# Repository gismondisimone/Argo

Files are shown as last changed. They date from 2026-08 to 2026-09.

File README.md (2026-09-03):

# ARGO - Halve The Time, Double The Help!

### A Smart System Created To Help Archaeologists.

---

## Renders
---

## BOM
All the bits and pieces needed can be found **[here](Production/BOM.md)**.

---

## What is This?
Argo is a **smart** system created to help **archaeologists**. It's the first of its kind to be able to digitalize archaeological fragments via scanning, create 3D models of the pieces and categorize them systematically, doing all of this quickly and **on-site**.

## Team
Composed of senior students Elisabetta Liliana Albanese and Rossella Fumai (Applied Sciences) and junior student Simone Gismondi (Traditional Track) from "Edoardo Amaldi" High School in Italy, our team discovered a passion for robotics through hands-on school projects in coding, mechanics, and electronics.

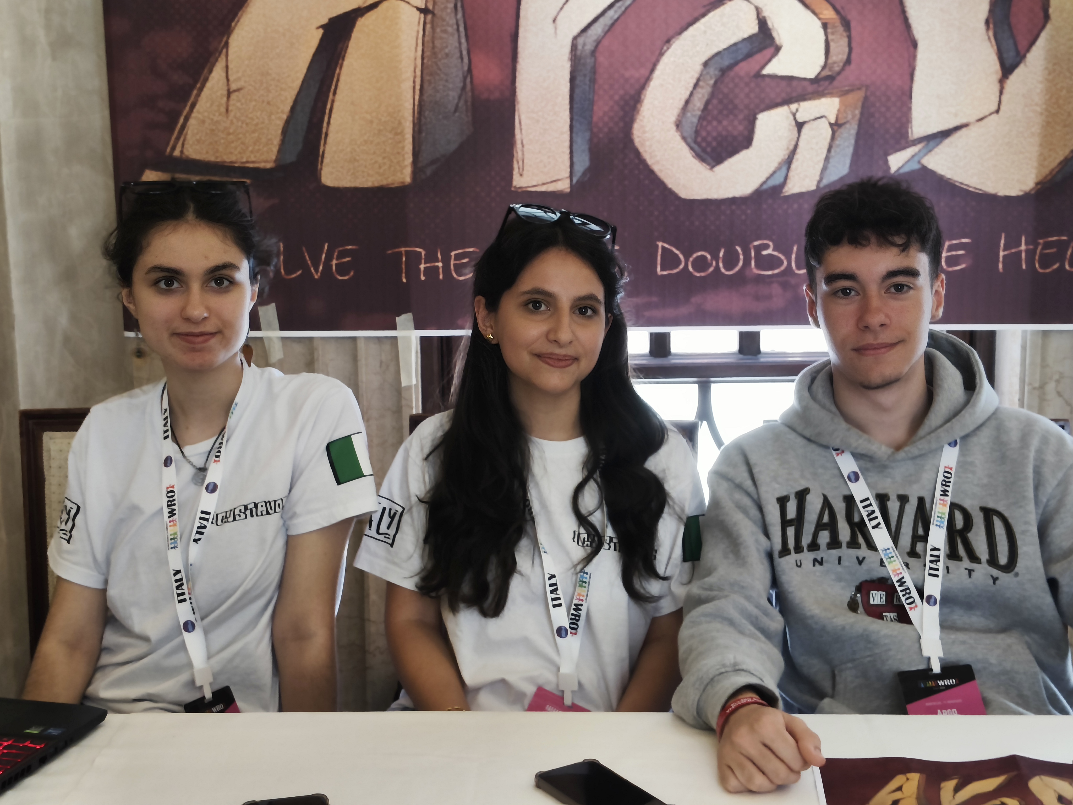
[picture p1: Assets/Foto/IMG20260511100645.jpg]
Team


- **Liliana** served as the project manager and took care of everything related to the communication of our project, from the documentation and presentation.
- **Simone** was responsible for the hardware engineering and 3D design of the prototype, ensuring the physical structure was functional and optimized.
- **Rossella** developed the software and engineered the Artificial Intelligence. She was also responsible for the graphics of our project.

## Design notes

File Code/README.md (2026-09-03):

# ✮Argo 2.0 - Croatia✮


> second prototype of the archeo-helper Argo, from Bitetto to Zagabria!

## ✶ Robot parts:
- **Rover module** - Movement unit, equipped with a map-remembering algorithm that follows you around and automatically finds it way back to the base when requested.
- **Buffer module** - Long and efficient sectionated conveyor belt that gets filled on site with artifacts and keeps them safe until scan.
- **scanner module** - The heart of the robot, where the phisical artefacts get scanned and become digitally accessibile.
- **Archeo-site** - Online archive where to publish all the scans with descriptions and make them accessibile to all archeologists around the world.
   > *psst, here's the demo! → *

## ✶ Rover module components:
- **x3 UWB boards** *(BU03 devkit)*
- **Raspberry pi4**
- **Raspberry Pico**
- **Arduino UNO**

## ✶ Buffer module components:

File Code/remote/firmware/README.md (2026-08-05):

# BU03-Kit remote firmware

`BU03_remote_controller.c` is custom STM32 firmware for the Ai-Thinker BU03-Kit. It does not use a Raspberry Pi or the factory AT firmware.

## Wiring

All connections must use 3.3 V logic.

| ST7789 pin | BU03-Kit pin |
| --- | --- |
| VCC | 3V3 |
| GND | GND |
| SCL/SCK | PB13 |
| SDA/MOSI | PB15 |
| CS | PB12 |
| DC | PA1 |
| RES/RST | PC13 |
| BL/BLK | 3V3 |

Connect buttons 1 through 6 respectively between `PB8`, `PB9`, `PB10`, `PB11`, `PA2`, `PA3` and GND. Internal pull-ups are enabled, so no external resistors are required.

## Packet protocol

Each button sends a channel-5, 6.8-Mbps UWB frame with type `0xA1` and a one-byte payload: `01` to `06`. Buttons 1–4 therefore send `01`–`04`.

The remote displays packets that use type `0xA2`; the bytes after that type are shown in hexadecimal. For example, the rover can return `A2 12 34 56`, which appears as `12 34 56` on the TFT.

The rover must use the same channel, UWB configuration, PAN ID `0xCADE`, and packet format. This is a new direct-radio protocol; it is not compatible with the factory AT ranging/positioning firmware.

## Build and flash

1. Download the official [STM32F103-BU0x SDK](https://gitee.com/Ai-Thinker-Open/STM32F103-BU0x_SDK).
2. Replace `Components/Main/main.c` in that SDK with `BU03_remote_controller.c`.
3. Open `Projects/USER/Project.uvprojx` in Keil MDK and select the `STM32F103C8` target.
4. Build it, then flash the generated `.hex` through the board’s SWD header with an ST-Link. Preserve a copy of the original factory firmware first if you may want to restore its AT/ranging behavior.

The stock SDK driver owns SPI1 and the pins connected to the BU03 module. The TFT uses SPI2 so it does not conflict with the UWB radio.

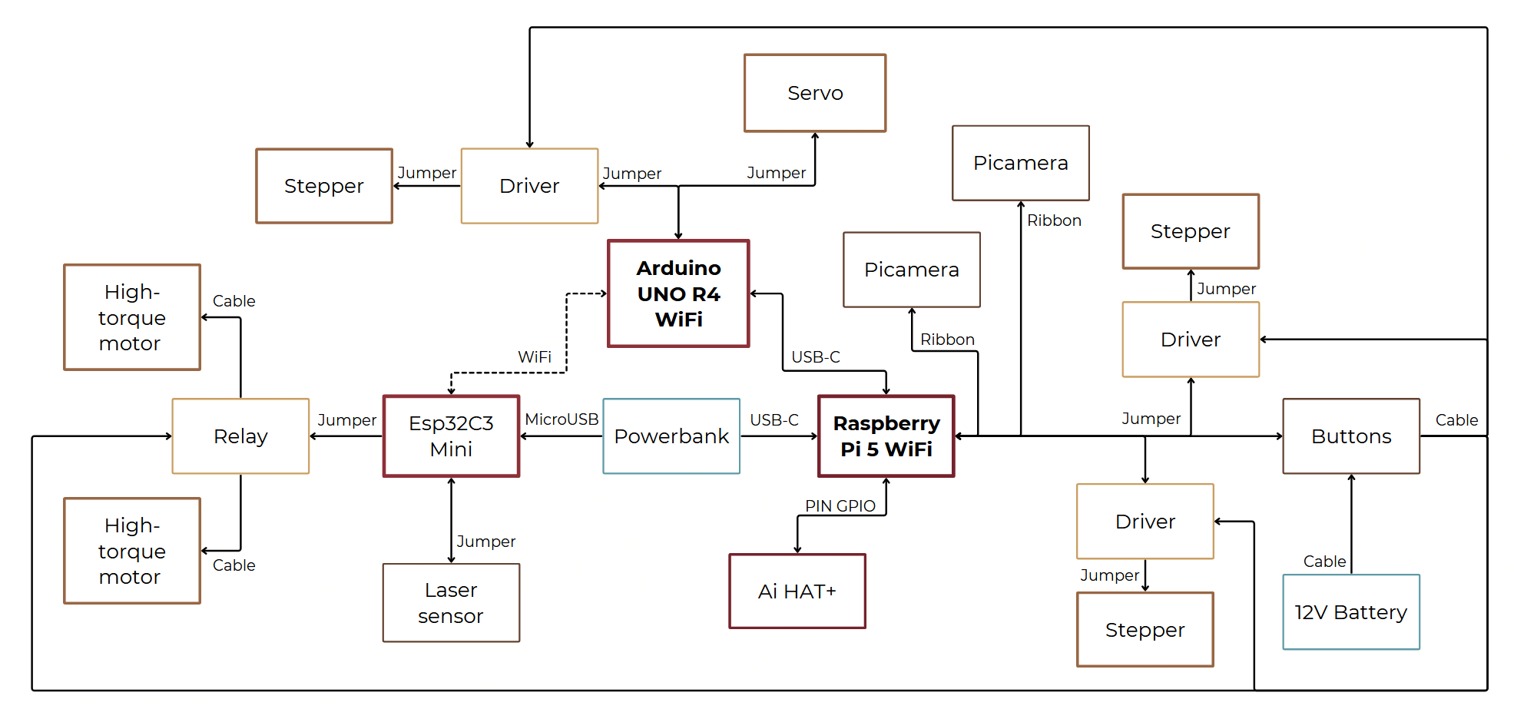
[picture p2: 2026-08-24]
Assets/diagram.png

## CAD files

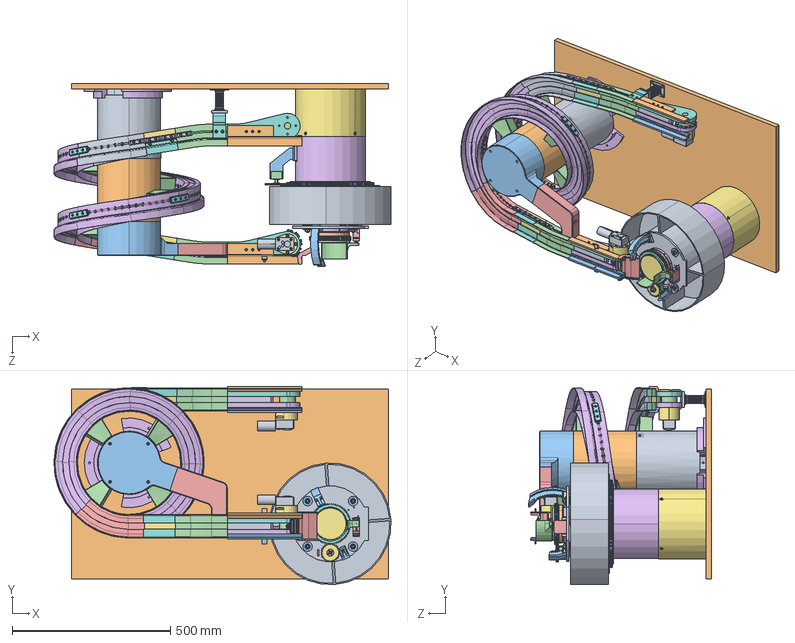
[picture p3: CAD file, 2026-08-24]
CAD/v.1/ELA-0002.STEP
1063.6 x 625.0 x 578.1 mm
ELP-0001
ELP-0002
ELP-0003
ELP-0004 x 6
ELP-0005
ELP-0006 x 10
ELP-0007 x 5
ELP-0008 x 6
Motore x 2
Flangia-di-accoppiamento x 2
ELP-0014 x 2
ELP-0015 x 2
6804-2RS x 4
ELP-0017 x 2
ELP-0018-1 x 2
ELP-0016 x 2
ELP-0019 x 2
ELP-0009
ELP-0010
ELP-0011
ELP-0012 x 8
ELP-0013 x 17
ELP-0020-1 x 2
ELP-0021-2 x 4
ELP-0022
ELP-0023
ELP-0024
ELP-0025
ELP-0026
ELP-0027 x 5
ELP-0029
ELP-0030-1_Metric - Spur gear 2M 63T 20PA 12FW ---S63N75H50L70N
ELP-0032
ELP-0033
ELP-0052
ELP-0034
ELP-0035
ELP-0038 x 3
ELP-0043
ELP-0044
ELP-0045
ELP-0047 x 4
plain washer grade a_din_PreviewCfg x 16
hex nut style 1 gradeab_din_Hexagon Nut ISO 4032 - M8 - W - N x 16
ELP-0048
ELP-0049
ELP-0050
ELP-0051_DIN - Spur gear 2M 136T 20PA 8.5FW ---S136A75H50L0.2N x 4
ELP-0053 x 4
ELP-0055_ISO - Spur gear 2M 34T 20PA 8FW ---S34A75H50L0.8N
ELP-0054
ELP-0042 x 3
ELP-0056
ELP-0039
ELP-0041-1_DIN - Spur gear 2M 28T 20PA 12FW ---S28A75H50L0.2N
ELP-0057
ELP-0058
ELP-0059
ELP-0061_ISO - Internal spur gear 2M 99T 20PA 8FW ---S93S210OD 1.0AF
ELP-0060_ISO - Spur gear 2M 11T 20PA 8FW ---S11A75H50L0.8N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

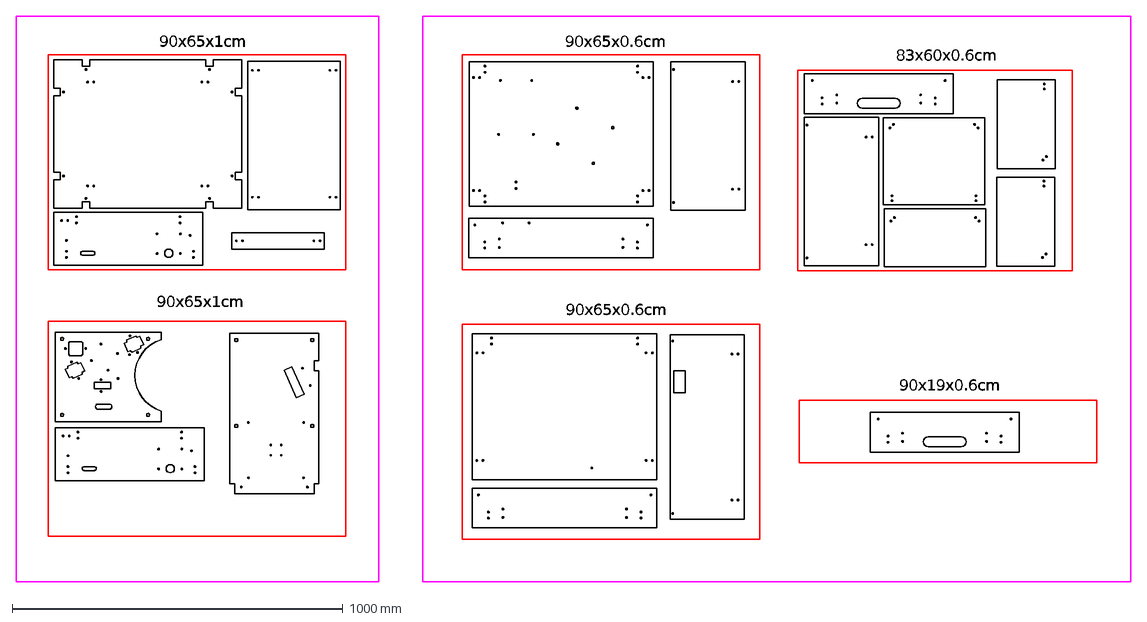
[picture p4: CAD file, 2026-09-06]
Production/Nesting.dxf
90x65x1cm
90x65x0.6cm
90x19x0.6cm
83x60x0.6cm

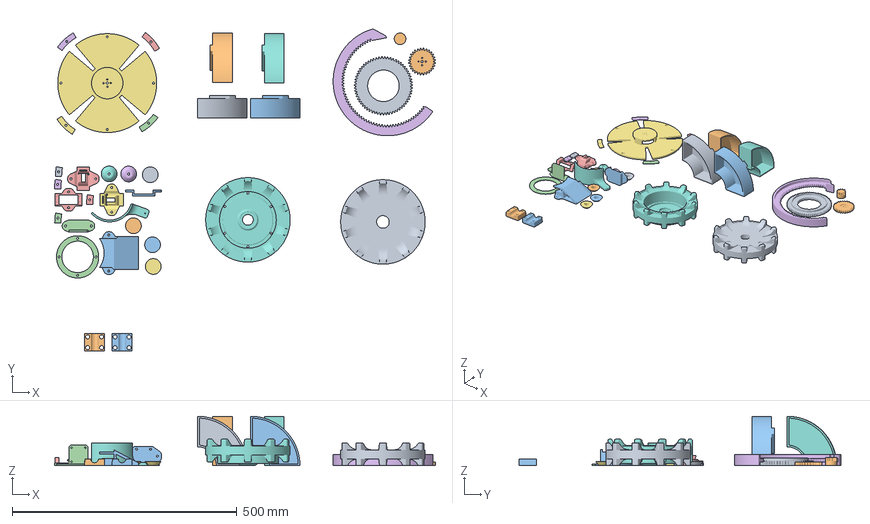
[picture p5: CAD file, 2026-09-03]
Production/Printables.3mf
847.8 x 716.8 x 110.0 mm
ARP-0068.STEP
ARP-0072.STEP
ARP-0073.STEP
ARP-0075.STEP
ARP-0076.STEP x 2
ARP-0077.STEP
ARP-0083.STEP x 4
ARP-0084.STEP
ARP-0085.STEP x 4
ARP-0088.STEP
ARP-0089.STEP
ARP-0090.STEP
ARP-0091.STEP
ARP-0092.STEP x 2
ARP-0086
ARP-0087 x 4
ARP-0098 x 4
ARP-0007-1
ARP-0008
ARP-0013 x 2

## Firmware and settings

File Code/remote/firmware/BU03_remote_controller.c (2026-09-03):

/*
 * BU03-Kit remote controller
 *
 * Target: Ai-Thinker BU03-Kit (STM32F103C8T6 + BU03/DW3000)
 * Base SDK: https://gitee.com/Ai-Thinker-Open/STM32F103-BU0x_SDK
 *
 * Replace Components/Main/main.c in that SDK with this file, then build its
 * Keil project.  The companion receiver must use the packet format below.
 */

#include <stdint.h>
#include <string.h>
#include <stm32f10x.h>
#include "deca_device_api.h"
#include "deca_regs.h"
#include "shared_defines.h"
#include "uwb.h"
#include "hal_drivers.h"

/* ------- Wiring: all signals are 3.3 V only --------------------------------
 * ST7789: SCK=PB13, MOSI=PB15, CS=PB12, DC=PA1, RST=PC13, BL=3V3.
 * Buttons 1..6: PB8, PB9, PB10, PB11, PA2, PA3, each connected to GND.
 * PB14 (SPI2 MISO) is unused. Do not use PA0/PA4..PA7/PB0/PB5: the BU03
 * radio uses these pins internally.
 */
#define TFT_CS_PORT GPIOB
#define TFT_CS_PIN  GPIO_Pin_12
#define TFT_DC_PORT GPIOA
#define TFT_DC_PIN  GPIO_Pin_1
#define TFT_RST_PORT GPIOC
#define TFT_RST_PIN GPIO_Pin_13

#define BUTTON_B_PORT GPIOB
#define BUTTON_B_PINS (GPIO_Pin_8 | GPIO_Pin_9 | GPIO_Pin_10 | GPIO_Pin_11)
#define BUTTON_A_PORT GPIOA
#define BUTTON_A_PINS (GPIO_Pin_2 | GPIO_Pin_3)

#define PAN_ID       0xCADE
#define REMOTE_ADDR  0x0001
#define BROADCAST    0xFFFF
#define FRAME_TYPE_BUTTON 0xA1
#define FRAME_TYPE_DISPLAY 0xA2 /* receiver sends ASCII/binary data to show */
#define MAC_HEADER_LEN 10
#define MAX_RX_BYTES  32

static const uint8_t button_codes[6] = {1, 2, 3, 4, 5, 6};
static uint8_t sequence_number;
static uint8_t display_data[MAX_RX_BYTES];
static uint8_t display_length;

/* Channel 5, 6.8 Mbps. The receiver must use exactly the same radio config. */
static dwt_config_t uwb_config = {
    5, DWT_PLEN_128, DWT_PAC8, 9, 9, 1, DWT_BR_6M8,
    DWT_PHRMODE_STD, DWT_PHRRATE_STD, (129 + 8 - 8),
    DWT_STS_MODE_OFF, DWT_STS_LEN_64, DWT_PDOA_M0
};
extern dwt_txconfig_t txconfig_options;

static void delay_ms(uint32_t ms)
{
    /* The SDK's Sleep() is a millisecond delay and is already calibrated. */
    while (ms--) Sleep(1);
}

static void clock_init(void)
{
    ErrorStatus hse_ok;
    RCC_DeInit();
    RCC_HSEConfig(RCC_HSE_ON);
    hse_ok = RCC_WaitForHSEStartUp();
    if (hse_ok == ERROR) while (1) { }
    FLASH_PrefetchBufferCmd(FLASH_PrefetchBuffer_Enable);
    FLASH_SetLatency(FLASH_Latency_2);
    RCC_HCLKConfig(RCC_SYSCLK_Div1);
    RCC_PCLK2Config(RCC_HCLK_Div1);
    RCC_PCLK1Config(RCC_HCLK_Div2);
    RCC_PLLConfig(RCC_PLLSource_HSE_Div1, RCC_PLLMul_9);
    RCC_PLLCmd(ENABLE);
    while (RCC_GetFlagStatus(RCC_FLAG_PLLRDY) == RESET) { }
    RCC_SYSCLKConfig(RCC_SYSCLKSource_PLLCLK);
    while (RCC_GetSYSCLKSource() != 0x08) { }
}

static uint8_t spi2_byte(uint8_t value)
{
    while (SPI_I2S_GetFlagStatus(SPI2, SPI_I2S_FLAG_TXE) == RESET) { }
    SPI_I2S_SendData(SPI2, value);
    while (SPI_I2S_GetFlagStatus(SPI2, SPI_I2S_FLAG_RXNE) == RESET) { }
    return (uint8_t)SPI_I2S_ReceiveData(SPI2);
}

static void tft_command(uint8_t command)
{
    GPIO_ResetBits(TFT_CS_PORT, TFT_CS_PIN);
    GPIO_ResetBits(TFT_DC_PORT, TFT_DC_PIN);
    spi2_byte(command);
    GPIO_SetBits(TFT_CS_PORT, TFT_CS_PIN);
}

static void tft_data(const uint8_t *data, uint16_t length)
{
    GPIO_ResetBits(TFT_CS_PORT, TFT_CS_PIN);
    GPIO_SetBits(TFT_DC_PORT, TFT_DC_PIN);
    while (length--) spi2_byte(*data++);
    GPIO_SetBits(TFT_CS_PORT, TFT_CS_PIN);
}

static void tft_init(void)
{
    GPIO_InitTypeDef gpio;
    SPI_InitTypeDef spi;
    const uint8_t madctl = 0x00, color_mode = 0x55;

    RCC_APB2PeriphClockCmd(RCC_APB2Periph_GPIOA | RCC_APB2Periph_GPIOB |
                           RCC_APB2Periph_GPIOC, ENABLE);
    RCC_APB1PeriphClockCmd(RCC_APB1Periph_SPI2, ENABLE);
    gpio.GPIO_Speed = GPIO_Speed_50MHz;
    gpio.GPIO_Mode = GPIO_Mode_AF_PP;
    gpio.GPIO_Pin = GPIO_Pin_13 | GPIO_Pin_15;
    GPIO_Init(GPIOB, &gpio);
    gpio.GPIO_Mode = GPIO_Mode_Out_PP;
    gpio.GPIO_Pin = TFT_CS_PIN;
    GPIO_Init(TFT_CS_PORT, &gpio);
    gpio.GPIO_Pin = TFT_DC_PIN;
    GPIO_Init(TFT_DC_PORT, &gpio);
    gpio.GPIO_Pin = TFT_RST_PIN;
    GPIO_Init(TFT_RST_PORT, &gpio);
    GPIO_SetBits(TFT_CS_PORT, TFT_CS_PIN);

    SPI_I2S_DeInit(SPI2);
    spi.SPI_Direction = SPI_Direction_2Lines_FullDuplex;
    spi.SPI_Mode = SPI_Mode_Master;
    spi.SPI_DataSize = SPI_DataSize_8b;
    spi.SPI_CPOL = SPI_CPOL_Low;
    spi.SPI_CPHA = SPI_CPHA_1Edge;
    spi.SPI_NSS = SPI_NSS_Soft;
    spi.SPI_BaudRatePrescaler = SPI_BaudRatePrescaler_2;
    spi.SPI_FirstBit = SPI_FirstBit_MSB;
    spi.SPI_CRCPolynomial = 7;
    SPI_Init(SPI2, &spi);
    SPI_Cmd(SPI2, ENABLE);

    GPIO_ResetBits(TFT_RST_PORT, TFT_RST_PIN);
    delay_ms(20);
    GPIO_SetBits(TFT_RST_PORT, TFT_RST_PIN);
    delay_ms(120);
    tft_command(0x01); delay_ms(150);       /* software reset */
    tft_command(0x11); delay_ms(120);       /* sleep out */
    tft_command(0x36); tft_data(&madctl, 1);
    tft_command(0x3A); tft_data(&color_mode, 1); /* RGB565 */
    tft_command(0x21);                       /* display inversion on */
    tft_command(0x29);                       /* display on */
}

static void tft_window(uint16_t x0, uint16_t y0, uint16_t x1, uint16_t y1)
{
    uint8_t value[4];
    value[0] = x0 >> 8; value[1] = x0; value[2] = x1 >> 8; value[3] = x1;
    tft_command(0x2A); tft_data(value, 4);
    value[0] = y0 >> 8; value[1] = y0; value[2] = y1 >> 8; value[3] = y1;
    tft_command(0x2B); tft_data(value, 4);
    tft_command(0x2C);
}

static void tft_fill(uint16_t colour)
{
    uint8_t pixel[2] = {colour >> 8, colour};
    uint32_t count = 240UL * 280UL;
    tft_window(0, 0, 239, 279);
    GPIO_ResetBits(TFT_CS_PORT, TFT_CS_PIN);
    GPIO_SetBits(TFT_DC_PORT, TFT_DC_PIN);
    while (count--) { spi2_byte(pixel[0]); spi2_byte(pixel[1]); }
    GPIO_SetBits(TFT_CS_PORT, TFT_CS_PIN);
}

/* A compact hexadecimal display is deliberate: it can show arbitrary binary
 * UWB payloads without assuming that received bytes are printable text. */
static const uint8_t hex_font[16][5] = {
    {0x1F,0x11,0x11,0x11,0x1F}, {0x00,0x12,0x1F,0x10,0x00},
    {0x1D,0x15,0x15,0x15,0x17}, {0x11,0x15,0x15,0x15,0x1F},
    {0x07,0x04,0x04,0x04,0x1F}, {0x17,0x15,0x15,0x15,0x1D},
    {0x1F,0x15,0x15,0x15,0x1D}, {0x01,0x01,0x1D,0x03,0x01},
    {0x1F,0x15,0x15,0x15,0x1F}, {0x17,0x15,0x15,0x15,0x1F},
    {0x1E,0x05,0x05,0x05,0x1E}, {0x1F,0x15,0x15,0x15,0x0A},
    {0x1F,0x11,0x11,0x11,0x11}, {0x1F,0x11,0x11,0x0A,0x04},
    {0x1F,0x15,0x15,0x15,0x11}, {0x1F,0x05,0x05,0x05,0x01}
};

static void tft_hex_byte(uint8_t value, uint16_t x, uint16_t y, uint8_t scale)
{
    uint8_t digit, col, row, sx, sy;
    for (digit = 0; digit < 2; digit++) {
        const uint8_t *glyph = hex_font[(digit == 0) ? value >> 4 : value & 0x0F];
        for (col = 0; col < 5; col++) for (row = 0; row < 5; row++) {
            if (glyph[col] & (1U << row)) {
                tft_window(x + (digit * 6 + col) * scale, y + row * scale,
                           x + (digit * 6 + col + 1) * scale - 1,
                           y + (row + 1) * scale - 1);
                GPIO_ResetBits(TFT_CS_PORT, TFT_CS_PIN);
                GPIO_SetBits(TFT_DC_PORT, TFT_DC_PIN);
                for (sx = 0; sx < scale; sx++) for (sy = 0; sy < scale; sy++) {
                    spi2_byte(0xFF); spi2_byte(0xFF);
                }
                GPIO_SetBits(TFT_CS_PORT, TFT_CS_PIN);
            }
        }
    }
}

static void show_data(void)
{
    uint8_t i;
    tft_fill(0x0000);
    /* First byte is the last pressed button; following bytes are received data. */
    for (i = 0; i < display_length && i < 16; i++)
        tft_hex_byte(display_data[i], (i % 8) * 30, 30 + (i / 8) * 50, 3);
}

static void buttons_init(void)
{
    GPIO_InitTypeDef gpio;
    RCC_APB2PeriphClockCmd(RCC_APB2Periph_GPIOA | RCC_APB2Periph_GPIOB, ENABLE);
    gpio.GPIO_Mode = GPIO_Mode_IPU;
    gpio.GPIO_Speed = GPIO_Speed_2MHz;
    gpio.GPIO_Pin = BUTTON_B_PINS;
    GPIO_Init(BUTTON_B_PORT, &gpio);
    gpio.GPIO_Pin = BUTTON_A_PINS;
    GPIO_Init(BUTTON_A_PORT, &gpio);
}

static int8_t button_pressed(void)
{
    static uint16_t old_state = 0x003F;
    uint16_t state = 0;
    uint8_t i;
    const uint16_t bmask[] = {GPIO_Pin_8, GPIO_Pin_9, GPIO_Pin_10, GPIO_Pin_11};
    for (i = 0; i < 4; i++) if (GPIO_ReadInputDataBit(GPIOB, bmask[i])) state |= 1U << i;
    if (GPIO_ReadInputDataBit(GPIOA, GPIO_Pin_2)) state |= 1U << 4;
    if (GPIO_ReadInputDataBit(GPIOA, GPIO_Pin_3)) state |= 1U << 5;
    for (i = 0; i < 6; i++) {
        if ((old_state & (1U << i)) && !(state & (1U << i))) {
            old_state = state;
            return (int8_t)i;
        }
    }
    old_state = state;
    return -1;
}

static void radio_init(void)
{
    port_set_dw_ic_spi_fastrate();
    reset_DWIC();
    delay_ms(2);
    while (!dwt_checkidlerc()) { }
    if (dwt_initialise(DWT_DW_INIT) == DWT_ERROR) while (1) { }
    if (dwt_configure(&uwb_config) == DWT_ERROR) while (1) { }
    dwt_configuretxrf(&txconfig_options);
    dwt_rxenable(DWT_START_RX_IMMEDIATE);
}

static void radio_send_button(uint8_t button)
{
    uint8_t frame[MAC_HEADER_LEN + 1];
    uint16_t frame_len = sizeof(frame);
    frame[0] = 0x41; frame[1] = 0x88; frame[2] = sequence_number++;
    frame[3] = PAN_ID & 0xFF; frame[4] = PAN_ID >> 8;
    frame[5] = BROADCAST & 0xFF; frame[6] = BROADCAST >> 8;
    frame[7] = REMOTE_ADDR & 0xFF; frame[8] = REMOTE_ADDR >> 8;
    frame[9] = FRAME_TYPE_BUTTON;
    frame[10] = button_codes[button];
    dwt_forcetrxoff();
    dwt_writetxdata(frame_len, frame, 0);
    dwt_writetxfctrl(frame_len + FCS_LEN, 0, 0);
    dwt_starttx(DWT_START_TX_IMMEDIATE);
    while (!(dwt_read32bitreg(SYS_STATUS_ID) & SYS_STATUS_TXFRS_BIT_MASK)) { }
    dwt_write32bitreg(SYS_STATUS_ID, SYS_STATUS_TXFRS_BIT_MASK);
    display_data[0] = button_codes[button];
    display_length = 1;
    show_data();
    dwt_rxenable(DWT_START_RX_IMMEDIATE);
}

static void radio_poll(void)
{
    uint32_t status = dwt_read32bitreg(SYS_STATUS_ID);
    uint16_t length;
    uint8_t frame[FRAME_LEN_MAX];
    if (status & SYS_STATUS_RXFCG_BIT_MASK) {
        length = dwt_read32bitreg(RX_FINFO_ID) & RX_FINFO_RXFLEN_BIT_MASK;
        dwt_write32bitreg(SYS_STATUS_ID, SYS_STATUS_RXFCG_BIT_MASK);
        if (length > FCS_LEN && length <= FRAME_LEN_MAX) {
            dwt_readrxdata(frame, length - FCS_LEN, 0);
            if (length > MAC_HEADER_LEN + FCS_LEN && frame[9] == FRAME_TYPE_DISPLAY) {
                display_length = length - FCS_LEN - MAC_HEADER_LEN;
                if (display_length > MAX_RX_BYTES) display_length = MAX_RX_BYTES;
                memcpy(display_data, &frame[MAC_HEADER_LEN], display_length);
                show_data();
            }
        }
        dwt_rxenable(DWT_START_RX_IMMEDIATE);
    } else if (status & SYS_STATUS_ALL_RX_ERR) {
        dwt_write32bitreg(SYS_STATUS_ID, SYS_STATUS_ALL_RX_ERR);
        dwt_rxenable(DWT_START_RX_IMMEDIATE);
    }
}

int main(void)
{
    int8_t button;
    SystemInit();
    clock_init();
    Hal_Driver_Init();       /* initializes SPI1 and the BU03/DW3000 wiring */
    tft_init();
    buttons_init();
    display_data[0] = 0;
    display_length = 1;
    show_data();
    radio_init();
    while (1) {
        radio_poll();
        button = button_pressed();
        if (button >= 0) {
            delay_ms(20);    /* debounce */
            if (button_pressed() < 0) radio_send_button((uint8_t)button);
        }
    }
}

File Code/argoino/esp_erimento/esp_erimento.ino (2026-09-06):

#include <WiFi.h>
#include <WiFiServer.h>

WiFiServer mentoServer(80);
String argoinoReq = "N/A";

const int infrar = 2;
const int motor = 10;
const int linearA = 7; //da cambiare
const int linearB = 6; //da cambiare
const int scanModule = 3; //da cambiare

const char* net = "Lil's Galaxy S22"; //da cambiare
const char* psw = "Nobodyson"; //da cambiare

String rpiTaxi = "10.118.94.140"; //da cambiare
String rpiScan = "10.118.94.140"; //da cambiare
const String localName = "mento";

bool waitin = true;
int scann = false;
int full = 0;

void setup() {
  pinMode(infrar, INPUT);
  pinMode(scanModule, INPUT);
  pinMode(motor, OUTPUT);
  pinMode(linearA, OUTPUT);
  pinMode(linearB, OUTPUT);
  digitalWrite(motor, LOW);
  digitalWrite(linearA, LOW);
  digitalWrite(linearB, LOW);

  Serial.begin(115200);

  // Set static IP
  IPAddress staticIP(10, 118, 94, 72);
  IPAddress gateway(10, 118, 94, 1);
  IPAddress subnet(255, 255, 255, 0);
  WiFi.config(staticIP, gateway, subnet);

  WiFi.begin(net, psw);
  Serial.print("Connessione in corso");
  while (WiFi.status() != WL_CONNECTED) {
    delay(500);
    Serial.print(".");
  }
  Serial.println("\nConnesso alla rete!");
  Serial.print("ssid: ");
  Serial.println(WiFi.SSID());
  IPAddress ip = WiFi.localIP();
  Serial.print("IP mento: ");
  Serial.println(ip);

  mentoServer.begin();
}

void loop() {
  scann = digitalRead(scanModule);
  if (WiFi.status() == WL_CONNECTED) {  
    if (scann == 0) { 
      if (waitin) {
        if (full < 30) {
          int dist = analogRead(infrar);
          Serial.println(dist);
          if (dist > 300) {
            Serial.println("Object detected");
            full = full + 1;
            sendTo("1000", rpiTaxi);
            digitalWrite(motor, HIGH);
            delay(3000);
            digitalWrite(motor, LOW);
            Serial.println("Made space.");
            sendTo(String(full), rpiTaxi);
          } else {
            digitalWrite(motor, LOW);
            Serial.println("libero");
            delay(100);
          }
        }else{
          Serial.print("Conveyor full! Please head back to the base to scan.");
          sendTo("2000", rpiTaxi);
        }
        delay(100);
      }
    } else {
      digitalWrite(motor, LOW);
      waitin = false;
      int empty = 30-full;
      digitalWrite(motor, HIGH);
      delay(empty*1000);
      digitalWrite(motor, LOW);
      for (int i = 0; i <= full; i++) {
        digitalWrite(linearA, HIGH);
        digitalWrite(linearB, LOW);
        delay(1000);
        digitalWrite(linearA, LOW);
        digitalWrite(linearB, HIGH);
        delay(1000);
        Serial.println("Piece on plate. Waiting");
        sendTo("1", rpiScan);

      }
    }

    delay(100);
    WiFiClient mentoclnt = mentoServer.available();
    //Serial.println("listening mode");

    if (mentoclnt) {
      Serial.println("connecting");
      String request = "";
      while (mentoclnt.connected()) {
        Serial.println("received");
        Serial.println("scanner free, restarting conveyor...");
        waitin = false; 
        digitalWrite(motor, HIGH);
        mentoclnt.println("HTTP/1.1 200 OK");
        mentoclnt.println("Connection: close");
        mentoclnt.println();
        break;
//        if (mentoclnt.available()) {
//          char c = mentoclnt.read();
//          request += c;
//
//          if (c == '\n') {
//            Serial.println(request);
//            argoinoReq = extractData(request);
//            if (argoinoReq == "oc") {
//              Serial.println("scanner free, restarting conveyor...");
//              waitin = false; 
//              digitalWrite(motor, HIGH);
//            }
//            mentoclnt.println("HTTP/1.1 200 OK");
//            mentoclnt.println("Connection: close");
//            mentoclnt.println();
//            break;
//          }
//        }
        delay(100);
      }
      mentoclnt.stop();
    }
  }
  delay(100);
}

void sendTo(const String& message, const String& receiver) {
  WiFiClient client;
  if (client.connect(receiver.c_str(), 80)) {
    client.print("GET /" + localName + "?data=" + message + " HTTP/1.1\r\n");
    client.print("Host: " + receiver + "\r\n");
    client.print("Connection: close\r\n\r\n");
    client.stop();
    Serial.println("Sent to " + receiver);
  } else {
    Serial.println("Failed to connect");
    while (!client.connect(receiver.c_str(), 80)) {
      delay(1000);
      Serial.println("Retrying connection to " + receiver);
    }
    client.print("GET /" + localName + "?data=" + message + " HTTP/1.1\r\n");
    client.print("Host: " + receiver + "\r\n");
    client.print("Connection: close\r\n\r\n");
    client.stop();
    Serial.println("Sent to " + receiver + " after retry");
  }
}

String extractData(String req) {
  int start = req.indexOf("data=") + 5;
  int end = req.indexOf(" ", start);
  return req.substring(start, end);
}

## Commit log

2026-08-24 Aggiunti i miei file
    [1100-0001-0048 rev1.SLDPRT, 1100-0002-0072 rev1.SLDPRT, 1101-0041-0328.SLDPRT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]
2026-09-03 Poduction v.1
    [ARP-0007-1.STEP, ARP-0008.STEP, ARP-0009.DXF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]
2026-09-03 Production v.1.1
    [ARP-0007-1.STEP, ARP-0008.STEP, ARP-0009.DXF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]
2026-09-03 Production v.1.2
    [ARP-0007-1.STEP, ARP-0008.STEP, ARP-0009.DXF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]
2026-09-06 Nesting v.1.2
    [Nesting.dxf]
2026-09-06 Printables v.1.2
2026-09-16 code 1.8.0
    [rpi4_swd.cfg]
2026-10-31 CAD 2.0
2026-10-31 CAD 2.1
